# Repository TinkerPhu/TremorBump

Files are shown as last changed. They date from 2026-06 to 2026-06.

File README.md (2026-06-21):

TremorBump

# Tremor-Synchronized Stimulation Project

> ⚠ **This device applies up to 40 V electrical stimulation to the human body.
> Read [SAFETY.md](SAFETY.md) before building or using it.**

**[Open Companion App](https://tinkerphu.github.io/TremorBump/CompanionApp/tremor_recorder.html)**

This project implements a wearable device that detects hand/arm tremor in
real time and delivers phase-locked electrical stimulation in sync with the
tremor cycle, plus a companion web app for recording, reviewing, and
exporting telemetry from the device over Bluetooth Low Energy (BLE).

**KUDOS to the following projects that were the main inspiration:**

- **[DIY Transcutaneous Spinal Stimulator Guide](https://www.scribd.com/document/766706842/An-easy-to-build-transcutaneous-electrical-stimulator-for-spinal-cord-stimulation-therapy)**
- **[OpenVstim](https://github.com/MonzurulAlam/OpenVstim)**

See [`docs/References.md`](docs/References.md) for more sources.

## AI-generated content

Most of the code and documents in this project are AI-generated, based on the references listed in [`docs/References.md`](docs/References.md).

## Background and motivation

The author of this project has **no medical background**. The motivation is personal: helping family members who suffer from Essential Tremor. The project is an attempt to understand the condition and build a practical, low-cost tool to explore phase-locked SES as a self-administered therapy.

The clinical background documents in `docs/` were compiled with the help of **[NotebookLM](https://notebooklm.google.com/)**, using the references listed in `docs/References.md` as source material. They represent a best-effort synthesis of the available literature — not medical advice.

- [`docs/SES_Overview.md`](docs/SES_Overview.md) — plain-language introduction: what SES is, how it works, expected sensation, and efficacy overview.
- [`docs/SES_Clinical_Reference.md`](docs/SES_Clinical_Reference.md) — full technical reference: neurophysiology, fiber targets, electrode placement, stimulation parameters, clinical protocol, and outcome data.

> **None of this constitutes medical advice.** Consult a qualified healthcare professional before using any electrical stimulation device.

**It consists of four parts:**

1. **Hardware** — a wearable unit built around the Adafruit QT Py ESP32-S3,
   comprising two subsystems:
   - *Sensing:* an Adafruit BNO055 IMU measures gyroscope and quaternion data
     to detect tremor axis, frequency, and phase in real time.
   - *Stimulation:* a boost converter raises the supply to up to 40 V DC,
     which an H-bridge switches across skin-contact electrodes to deliver
     charge-balanced biphasic pulses synchronized to the tremor cycle.
2. **Tremor detection firmware** (`tremor_detection.py`) — runs on the device,
   detects tremor frequency/axis from the IMU, and drives the H-bridge to
   deliver biphasic stimulation pulses synchronized to the tremor.
3. **BLE telemetry** (`ble_telemetry.py`) — a custom BLE GATT service that
   advertises as `TREMOR` and streams live detector state to nearby devices.
4. **Tremor Recorder web app** (`tremor_recorder.html`) — a single-file,
   offline-capable HTML/JS app (Web Bluetooth + IndexedDB) for pairing with
   the device, recording sessions, charting live/aggregated data, and
   exporting/sharing results.

This is experimental code intended for use on isolated test hardware only.

```
TremorBump/
├── CircuitPython/          # Firmware — copy contents to the CIRCUITPY drive
│   ├── code.py
│   ├── tremor_detection.py
│   ├── ble_telemetry.py
│   ├── settings.toml
│   └── lib/                # Required CircuitPython libraries
├── CompanionApp/
│   ├── tremor_recorder.html
│   ├── manifest.json       # PWA manifest
│   ├── sw.js               # Service worker (offline cache)
│   ├── icon-192.png
│   └── icon-512.png
├── hardware/
│   ├── BOM.md              # Bill of materials
│   ├── TremorBumpBox.stl   # Main enclosure
│   ├── TremorBumpCog.stl
│   └── TremorBumpSensorBox.stl
└── docs/
    ├── References.md
    ├── SES_Overview.md
    ├── SES_Clinical_Reference.md
    └── conductive_electrode_gel_recipe.md
```

## Hardware required

- **Adafruit QT Py ESP32-S3** (4MB Flash / 2MB PSRAM variant,
  board ID `adafruit_qtpy_esp32s3_4mbflash_2mbpsram`). BLE is required, so the
  ESP32-S2 variant (no Bluetooth) will not work.
- **Adafruit BNO055** 9-DOF absolute orientation IMU, connected via I2C
  (`board.SCL` / `board.SDA`), used in NDOF fusion mode for gyro + quaternion
  data.
- **Boost converter** that steps the supply up to as much as **40 V DC**,
  feeding the H-bridge so it can drive the stimulation electrodes at
  therapeutic voltage.
- **H-bridge** driver for the stimulation electrodes, connected to
  `board.MOSI` (h_bridge_1) and `board.MISO` (h_bridge_2), switching the
  boosted 40 V supply to produce the stimulation waveform described below.
- **Stimulation electrodes** with conductive gel for skin contact. A DIY
  saline/glycerin/xanthan gel recipe is provided in
  [`docs/conductive_electrode_gel_recipe.md`](docs/conductive_electrode_gel_recipe.md).
- Onboard **NeoPixel** LED, used to indicate detector state (unlocked /
  locking / locked / holdover) and stimulation polarity.
- A BLE-capable computer or phone with a Chromium-based browser (Chrome /
  Edge) supporting Web Bluetooth, to run `tremor_recorder.html`.

## Firmware: required libraries

CircuitPython **10.2.0** with the following libraries in `lib/`:

- `adafruit_ble` — BLE radio, advertising, GATT services/characteristics
- `adafruit_bno055` — BNO055 IMU driver (gyro + quaternion)
- `adafruit_register` — register access helpers (dependency of the BNO055
  driver)
- `adafruit_pixelbuf` and `neopixel` — onboard NeoPixel status LED

Plus the CircuitPython built-in modules `board`, `busio`, `digitalio`,
`supervisor`, `math`, `time`, and `struct`.

The firmware entry point is `code.py`, which simply does
`import tremor_detection`.

## How tremor detection works (`tremor_detection.py`)

The detector samples the BNO055 gyroscope at **75 Hz** and runs a state
machine with four states:

- **UNLOCKED** — no tremor signal detected yet.
- **LOCKING** — a candidate tremor axis and frequency are being established;
  requires several alternating zero-crossings (4 from cold start, 2 when
  re-locking after holdover) within a timeout.
- **LOCKED** — tremor axis, frequency, and phase are tracked continuously;
  stimulation bursts are scheduled phase-correctly at each detected
  zero-crossing, with dead-reckoning between crossings.
- **HOLDOVER** — if the signal is lost while locked, stimulation continues at
  the last known frequency (at reduced duty cycle) via dead-reckoning for up
  to 5 seconds before falling back to UNLOCKED.

Key processing steps per sample:

1. Remove slowly-adapting gyro DC bias.
2. Optionally rotate gyro readings into world frame using the BNO055
   quaternion, so arm movement doesn't distort the tremor axis estimate.
3. Track the dominant tremor axis with a 3-D direction EWMA (fast time
   constant while locking, slow once locked).
4. Project motion onto that axis and track an amplitude envelope; detect
   hysteretic zero crossings with linear interpolation for precise timing.
5. Estimate tremor frequency (2–8 Hz) from alternating half-periods and use
   it to phase-correct the stimulation schedule.

When a stimulation event fires, `run_biphasic_burst()` drives the H-bridge
with a symmetric biphasic pulse train (250 µs phases, 1 µs interphase gap,
200 Hz internal pulse rate) for a duration proportional to the current tremor
period and a configurable duty cycle (halved during holdover).

### Stimulation waveform

A boost converter raises the device's supply to up to **40 V DC**. The
H-bridge switches this 40 V rail across the wrist electrodes to produce a
**biphasic (alternating-polarity) square-wave pulse train**: each pulse
consists of a 250 µs positive phase, a 1 µs interphase gap, and a 250 µs
negative phase, repeating at an internal pulse rate of 200 Hz. This biphasic
shape keeps the pulses charge-balanced (no net DC component), which is the
standard approach for safe transcutaneous nerve stimulation. Bursts of these
pulses are timed to coincide with the detected tremor cycle (locked) or its
extrapolated continuation (holdover), with a burst duration of
`duty_cycle / tremor_hz` — i.e. a fixed fraction (12.5%, or 6.25% during
holdover) of each tremor period — so the stimulation pulses the wrist nerves
in sync with, and proportional to, the ongoing tremor.

The onboard NeoPixel shows blue (unlocked), yellow (locking), off
(locked/holdover, with brief flashes on each stimulation burst showing
polarity).

## BLE telemetry protocol (`ble_telemetry.py`)

The device advertises as **`TREMOR`** with a custom 128-bit GATT service:

- Service UUID: `7f6d0001-6f7a-4f4e-9a8b-3b7f4b000001`
- Telemetry characteristic UUID: `7f6d0002-6f7a-4f4e-9a8b-3b7f4b000001`
  (read + notify)

The device name is placed in the BLE scan response (not the main
advertisement) so the custom service UUID fits in the primary advertisement
packet, allowing Web Bluetooth to discover the service by UUID.

While connected, the device sends a **13-byte, little-endian notify packet**
at 2 Hz (`BLE_NOTIFY_HZ`):

| Field | Type | Notes |
|---|---|---|
| `device_t_ms` | uint32 | raw device milliseconds, wraps ~49 days |
| `state_code` | uint8  | 0=UNLOCKED 1=LOCKING 2=LOCKED 3=HOLDOVER, 255=unknown |
| `sched_hz_x100` | uint16 | scheduling frequency × 100 (0.01 Hz resolution) |
| `tremor_hz_x100`| uint16 | measured tremor frequency × 100 (0.01 Hz resolution) |
| `mag_env_x10` | uint16 | 3-D gyro magnitude envelope × 10 (0.1 deg/s resolution) |
| `stim_count` | uint16 | cumulative stimulation count, wraps at 65535 |

The ESP-IDF BLE stack runs as a background FreeRTOS task, so the connection
stays alive even during the brief (~30 ms) blocking stimulation bursts.

## Hosting the web app (GitHub Pages + PWA)

The companion app is a fully static single-file app and can be hosted for
free on GitHub Pages.

### Enable GitHub Pages

1. Go to your repo on GitHub → **Settings** → **Pages**.
2. Source: **Deploy from a branch** → `main` → `/ (root)` → **Save**.
3. After a minute the app will be live at:
   `https://<your-username>.github.io/<repo-name>/CompanionApp/tremor_recorder.html`

GitHub Pages serves over HTTPS, which is required for both Web Bluetooth and
PWA installation.

### Install as a mobile app (Android)

Open the URL above in **Chrome on Android**, then tap the browser menu →
**Add to Home screen**. The app installs as a standalone icon with no browser
chrome, caches itself for offline use, and connects to the device over BLE
exactly as in the browser.

> **iOS note:** Web Bluetooth is not supported on iOS (Safari or Chrome on
> iPhone/iPad). The app can be added to the home screen on iOS but will not
> be able to connect to the device.

## Tremor Recorder web app (`tremor_recorder.html`)

A single-file, no-build-step, offline-capable web app (HTML + CSS + vanilla
JS) that connects to the `TREMOR` device over Web Bluetooth, records
telemetry sessions, and lets you review/export them. Works on desktop
(Chrome/Edge) and mobile Chrome on Android.

### Pairing & connection

- The device picker is filtered to devices whose advertised name starts with
  `TREMOR`, using `filters: [{ namePrefix: "TREMOR" }]`.
- The GATT connection is kept open across recording sessions (not
  re-paired/torn down after each stop), and silently reconnects if dropped.

### Screens

- **Start** — primary card with status line, a large "Start recording" button
  and a "Sessions" button; secondary card (scroll to reach) with
  Export / Admin / Settings and an optional "Run simulated session" button.
- **Recording** — primary card with large live Magnitude and Tremor frequency
  tiles, a "Stop & save" button, and a status/error line, all fitting on
  screen without scrolling; secondary card (scroll to reach) shows
  Stimulation count, Sched frequency, State, and Samples recorded.
- **Session saved** — large "Start new recording" button (reuses the existing
  BLE connection, or pairs first if needed) plus a summary and a link to
  review the saved session.
- **Review** — shows session summary and two SVG charts (Tremor frequency,
  Magnitude) plotting the per-interval average as a line with the min/max
  range as a shaded band. The Y-axis is scaled to 80%–120% of the average's
  min/max to avoid outlier samples dominating the scale.

### Data storage (IndexedDB: `tremor_recorder_db`)

- `sessions` — one record per recording session (start/stop times, device
  name, disconnect reason, config snapshot, sample count).
- `samples` — one record per telemetry packet received (timestamps, state,
  scheduled/tremor frequency, magnitude, stim count).
- `aggregates` — per-interval (default 10 s, configurable) min/avg/max
  statistics for tremor frequency and magnitude, plus active-stim coverage.

### Export & sharing

- CSV export of raw samples and JSON export of session summaries/aggregates.
- On desktop, both exports download as files.
- On mobile, "Share raw samples (CSV)" and "Share summary (JSON)" open the
  native share sheet (the JSON is shared as a `.txt` file due to Chromium
  share-target restrictions on `.json`/`application/json`).

### Simulation mode

Appending `?simulate=1` to the URL enables a "Run simulated session" button
that generates synthetic telemetry without requiring a real device — useful
for UI testing.

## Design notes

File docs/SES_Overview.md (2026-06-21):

# Sensory Electrical Stimulation (SES) — Overview and Clinical Background

Sensory Electrical Stimulation (SES) is a non-invasive neuromodulation technique that delivers low-level electrical currents through the skin at intensities below the motor threshold — providing sensory feedback without causing muscles to twitch or contract. This project uses SES to target **Essential Tremor (ET)**, the most common movement disorder in older adults, characterised by a rhythmic action/postural tremor of the hands at 5–8 Hz.

> SES has also been studied as a therapy for Parkinson's disease (PD) tremor, and the TremorBump device could in principle be applied there as well. However, ET is the focus of this project.

## How SES Works

Surface electrodes are placed over major nerves at the wrist (median and radial nerves) or over motor points on the forearm muscles. These electrodes deliver electrical pulses — often organised into high-frequency bursts — to disrupt pathological signals in the Cerebello-Thalamo-Cortical (CTC) circuit, which governs tremor amplitude in ET. By sending artificial sensory signals into this circuit, SES can "jam" or dephase the rhythmic oscillations that drive the involuntary hand movements.

## Expected Sensation

The patient should feel a **strong but comfortable tingling or tickling** sensation in the hand or fingers. Intensity must be set individually to stay at this sensory level — it should never cause an electric shock sensation or visible muscle contraction.

## Therapy Sessions

| Parameter | Typical value |
|---|---|
| Session length | 20–40 minutes |
| Frequency | 3× per week to daily |
| Duration of effect | Immediate; can persist >1 hour after stimulation ends |

Repeated daily use over months does not appear to lead to a loss of the lasting post-stimulation effect.

For the full technical detail — fiber types, electrode landmarks, stimulation parameters, and clinical outcomes — see [`SES_Clinical_Reference.md`](SES_Clinical_Reference.md).

## Estimated Efficacy

The figures below come primarily from studies on PD and general tremor populations, as large-scale ET-specific SES trials remain limited. The underlying mechanism (CTC circuit modulation) is shared with ET, so the results are considered indicative.

| Scenario | Tremor reduction |
|---|---|
| General SES | 35–48% average reduction |
| Calibrated therapies (e.g. TAPS) | >90% of patients see some reduction; majority achieve ≥50% decrease in tremor power |
| Phase-locked stimulation, severe tremors | 60–65% reduction in tremor power |
| Combined with physical therapy, suitable responders | Up to 83% average magnitude decrease |

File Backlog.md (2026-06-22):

# Backlog

---

## Main Goal

The current firmware fires a stimulation burst at **every** zero-crossing of the detected tremor angular velocity — i.e. at both π/2 and 3π/2 per cycle. This made sense as a placeholder and is correct for a future dual-channel 4-electrode system where the two channels fire in antiphase. For the current **single-channel 2-electrode system it is clinically wrong**: it stimulates twice per tremor cycle, which disrupts the phase-lock rather than reinforcing it.

**The goal of all three features below is to make the device fire at exactly one zero-crossing per tremor cycle — the one where the arm is moving closest to the body — and to determine that zero-crossing automatically from the sensor data and a one-time arm-side configuration set in the companion app.**

If arm side is not configured, the device does **not** stimulate at all. There is no automatic detection, no fallback to both phases, and no ambiguous state. The companion app is the right place to set and confirm arm side.

The three features must be delivered in order. Each is independently testable.

---

## Feature 1 (Prerequisite): BLE Settings Characteristic

### Goal

Allow the companion app to read and write persistent device settings over BLE. This is the communication layer that all subsequent features depend on. Nothing else in this backlog can be built without it.

### Context

The existing BLE GATT service (`7f6d0001`) has one characteristic:
- `7f6d0002` — telemetry, **notify + read**, device → app, 13 bytes (unchanged).

A second characteristic is added to the same service:
- `7f6d0003` — settings, **read + write**, bidirectional, 8-byte versioned struct.

The telemetry packet is **not** extended. Settings are read once on connect and trusted for the duration of the session. The session record stores the settings bytes as a header so every recording is self-describing.

### Settings Struct v1

All bytes little-endian. Total: 8 bytes.

| Byte | Field | Type | Values | Default |
|---|---|---|---|---|
| 0 | `struct_version` | uint8 | 1 | 1 |
| 1 | `arm_side` | uint8 | 0 = not set, 1 = left, 2 = right | 0 |
| 2 | `fire_polarity_override` | uint8 | 0 = auto, 1 = positive crossing, 2 = negative crossing | 0 |
| 3–7 | *(reserved)* | uint8 × 5 | 0xFF | 0xFF |

`struct_version` must be incremented whenever the layout changes. App and firmware both check it and handle mismatches gracefully.

### App ↔ Device Protocol

**On every BLE connection (before Settings screen is usable):**
```
App connects
  → Read 7f6d0003 (8 bytes)
  → Check struct_version
      - Unknown version (device newer than app): show notice, disable writes, show read-only values
      - Known version: update Settings UI, cache struct in session memory as deviceSettings
```

**On every user-initiated setting change:**
```
User changes value in Settings screen
  → Merge change into cached deviceSettings struct (never build struct from UI state alone)
  → Write full 8-byte struct to 7f6d0003 (write-with-response)
  → Wait 300 ms
  → Read back 7f6d0003
  → Compare: match → show "Saved"; mismatch → show error, revert UI to read-back value
```

**Settings are never stored in the app's localStorage or IndexedDB. The device NVM is the single source of truth. The app always reads from the device on connect.**

### Session Data Header

When a session starts, the app reads the current `deviceSettings` object (already cached from connect-time read) and stores it as part of the session record in IndexedDB:

```
session.deviceSettings = {
  structVersion: 1,
  armSide: 1,          // 0 = not set, 1 = left, 2 = right
  firePolarityOverride: 0,
  rawBytes: [1, 1, 0, 255, 255, 255, 255, 255]  // full 8-byte struct as recorded
}
```

This is included in every JSON export under `session.deviceSettings`. It means any recording is fully self-describing: the settings active during that session are always available, regardless of what the device is configured to later.

### Firmware Implementation Plan (`ble_telemetry.py`)

- Add `7f6d0003` to the existing GATT service with read + write-with-response permissions.
- On **read**: assemble 8-byte struct from `microcontroller.nvm[0:8]`. If any byte is 0xFF (uninitialised), substitute the field's default before returning.
- On **write**: validate `struct_version` matches firmware's expected version — reject silently if not. Validate each field is within allowed range — clamp out-of-range values. Write validated fields to `microcontroller.nvm[0:8]`. Apply fields that take immediate effect (see Feature 2 for `arm_side`).
- Reserve `microcontroller.nvm[0:8]` exclusively for this struct. Any future NVM use starts at index 8.

### Companion App Implementation Plan (`tremor_recorder.html`)

- On BLE connect, read `7f6d0003` immediately. Settings screen shows a loading state until read completes.
- Cache result in session-scoped JS object `deviceSettings`. All writes merge into this object.
- On session start (`startRecording()`): copy current `deviceSettings` into the new session record.
- Settings screen gains a "Device settings" section (separate from the existing app-local aggregate interval / stim-window settings which remain in localStorage):
  - **Arm side**: Left / Right / Not set (maps to 1 / 2 / 0)
  - **Phase override**: Auto / Force positive crossing / Force negative crossing (collapsible, labelled "research use only")
- Write → read-back → confirm / error as per protocol above.
- On BLE disconnect during a write in progress: show error, re-read on reconnect before enabling further writes.
- Session export JSON: include `deviceSettings` under each session.

### Documentation Plan

- Help screen and `docs/`: explain that "Device settings" are stored on the device, survive power cycles, and are separate from app-local session settings. Explain that every exported recording carries the device settings that were active during that session.

### Open Questions

- [ ] 300 ms read-back delay: verify empirically that `microcontroller.nvm` write completes within this window on the QT Py ESP32-S3.
- [ ] Write-with-response: confirm CircuitPython's `adafruit_ble` supports this on the peripheral side.
- [ ] Security: no write protection planned for now. Revisit if used in a clinical setting.

---

## Feature 2: Arm-Side Configuration

### Goal

The device must know which arm it is on (left or right) so that Feature 3 can select the correct stimulation phase. The arm side is set once in the companion app and stored persistently in device NVM. If it is not set, the device does not stimulate.

### User Story

> As a patient or carer, I configure which arm the device is on once in the companion app. The device remembers it across power cycles. If it is not set, the app tells me clearly and no stimulation happens until I configure it.

### Mechanism

1. Patient (or carer) connects the companion app.
2. Opens Settings → selects Left or Right arm.
3. App writes `arm_side` field to the device via `7f6d0003`.
4. Firmware writes to NVM.
5. On every subsequent power-on, device reads NVM and has arm side immediately. No calibration, no detection, no posture.

If `arm_side == 0` (not set): the app shows a clear, prominent message — "Arm side not configured. Go to Settings to set it before starting a session." The Start recording button is disabled until arm side is set.

### Firmware Implementation Plan (`tremor_detection.py` + `ble_telemetry.py`)

- `tremor_detection.py`: on startup, read `microcontroller.nvm[1]` into `arm_side`. Expose `arm_side` to the BLE module.
- `ble_telemetry.py`: when the settings characteristic receives a write with a new `arm_side` value, write to `microcontroller.nvm[1]` and update the RAM variable immediately (takes effect in the current session without restart).
- `arm_side = 0`: the device reaches LOCKED state but does not call `run_biphasic_burst()`. No stimulation occurs. This is not an error state — it simply means the device has not been configured yet.

### Companion App Implementation Plan

- On connect: read `7f6d0003`. If `arm_side == 0`: show a clear prominent message on the start screen "Arm side not set — configure in Settings before recording." Disable the "Start recording" button.
- Start recording is only enabled when `arm_side` is 1 or 2.
- Settings screen: arm-side selector as described in Feature 1.
- Session export: `deviceSettings.armSide` is in every session record (via Feature 1 session header).

### Documentation Plan

- Help screen: explain that arm side must be set once before first use. Explain what happens if it is not set (no stimulation, app shows message).
- Manual: add sensor placement rule — device must always be on the **dorsal (back) side** of the wrist, with the marked end pointing toward the hand. This is a hard constraint: wrong placement inverts the phase selection in Feature 3.

### Open Questions

- [ ] NVM byte index: `arm_side` is at `microcontroller.nvm[1]` (byte 1 of the settings struct, after `struct_version` at byte 0). Confirm all startup code reads byte 1, not byte 0.
- [ ] "Not set" UX: should the Settings screen open automatically if arm side is not set when first connecting? Consider an onboarding flow for first use.

---

## Feature 3: Phase-Correct Stimulation (Single Phase per Cycle)

### Goal

This is the main goal of the entire backlog. Once the arm side is known (Feature 2), the firmware derives the correct zero-crossing polarity (positive or negative) to use as the stimulation trigger and fires **once per tremor cycle** at that crossing only.

### User Story

> As a patient, I want the device to fire one stimulation pulse per tremor cycle — at the moment my arm is moving closest to my body — so that the therapy correctly interrupts the tremor feedback loop instead of reinforcing it.

### Acceptance Criteria

1. With arm side set and sensor correctly placed (dorsal, mark toward hand), stimulation fires exactly once per tremor cycle.
2. The firing zero-crossing corresponds to the arm moving toward the body.
3. Behaviour is mirrored correctly for left vs. right arm.
4. If arm side is not set (`arm_side == 0`): device locks on to tremor but does not stimulate. App shows "Arm side not set — no stimulation active."
5. The phase can be overridden manually from the app Settings (research/diagnostic use only).
6. Stimulation count in telemetry increments once per cycle (previously twice).

### Phase Selection Logic

The BNO055 gyroscope measures angular velocity in its own sensor frame. The firmware already identifies the dominant tremor axis as a 3D unit vector. The angular velocity projected onto this axis oscillates at the tremor frequency; zero-crossings mark the turning points of the tremor cycle.

The two zero-crossings per cycle are:
- **Positive-going** (velocity crosses zero from negative to positive): arm reverses direction one way.
- **Negative-going** (velocity crosses zero from positive to negative): arm reverses direction the other way.

Which one corresponds to "arm moving toward body" depends on:
1. **Arm side (left/right)**: mirrors the anatomical rotation axis.
2. **Sensor placement**: sensor on the dorsal side with mark toward the hand — this fixes the sign convention. This is a hard constraint documented in Feature 2.

> ⚠ **Posture constraint for phase computation:**  
> The gravity vector provides up/down orientation. "Toward the body" is a roughly horizontal direction. For the derivation to work reliably, the arm should be approximately horizontal (extended forward or to the side) at the moment the device locks in. The firmware computes `fire_polarity` once at the LOCKED transition using the gravity vector at that instant. If the arm is near-vertical at lock-in, the gravity projection onto the tremor plane is weak — treat this as a degenerate case and do not stimulate until re-lock with a better posture.

**Derivation (to be validated on hardware before coding):**
1. At LOCKED transition: read gravity vector `g` and dominant tremor axis unit vector `t` (both from BNO055 NDOF output).
2. Project `g` onto the plane perpendicular to `t`: `g_perp = g − (g·t)t`. This gives the "downward" direction as seen from the tremor axis.
3. The "toward body" rotational direction = cross product of `t` and `g_perp`, sign-corrected for arm side (negated for left arm).
4. Compare this direction to the sign of the angular velocity projection at lock-in to select `fire_polarity`.

### Firmware Implementation Plan (`tremor_detection.py`)

- On transition to `LOCKED` state:
  - If `arm_side == 0` (not set): set `fire_polarity = NONE`. Do not call `run_biphasic_burst()` at any zero-crossing.
  - If `arm_side` is known (1 or 2) and `fire_polarity_override == 0`: compute `fire_polarity` using the derivation above.
  - If `fire_polarity_override != 0`: use override value directly.
  - If gravity projection is too weak (degenerate posture): set `fire_polarity = NONE`, do not stimulate.
- In `LOCKED` and `HOLDOVER` states: only call `run_biphasic_burst()` at zero-crossings matching `fire_polarity`. Skip all other crossings.
- Re-compute `fire_polarity` at each re-lock. The arm may have moved.
- **Do not extend the telemetry packet.** `fire_polarity` and `arm_side` are available to the app via the settings characteristic and the session header.

### Companion App Implementation Plan

- Recording screen: show "Arm side" (from `deviceSettings` cached at connect time) as a small read-only status field. No telemetry bytes needed — this comes from the settings read.
- If `deviceSettings.armSide == 0` and a recording is started (should be blocked by Feature 2, but as defence): show a persistent red warning on the recording screen "Arm side not set — device is not stimulating."
- Settings screen "Phase override" (from Feature 1): Auto / Force positive / Force negative. Labelled "Research / diagnostic use only."
- Session export: `deviceSettings.firePolarityOverride` is already in the session header from Feature 1.
- Stimulation count metric: relabel from "Stimulation count" to "Stimulation bursts".

### Documentation Plan

- Help screen: brief explanation that the device selects the stimulation phase automatically from the sensor and arm-side configuration. No user action needed beyond setting arm side once.
- Help screen: "If arm side is not set, the device detects your tremor but does not deliver stimulation. Set arm side in Settings."
- Manual: technical note on the phase-selection mechanism.

### Dependencies

- Feature 3 cannot start until Feature 2 is complete and `arm_side` is reliably written to NVM and read by firmware.
- **The phase derivation math must be validated on paper and on the physical device before writing any firmware.** Document the exact BNO055 axis convention (X/Y/Z vs. anatomical forearm axes) first.

### Open Questions

- [ ] Work out and document the BNO055 coordinate frame. Which sensor axis is along the forearm, which is lateral, which is dorsal-normal. This is the foundation of the entire derivation — get it wrong and the phase is inverted.
- [ ] Define "toward body" precisely for the expected tremor type. Essential Tremor typically involves pronation/supination and flexion/extension of the wrist. Is the therapeutically relevant motion adduction or flexion? May need per-patient validation in early trials.
- [ ] Degenerate posture threshold: how small does `|g_perp|` need to be before we consider the posture degenerate? Suggested: if `|g_perp| < 1.0 m/s²` (arm within ~6° of vertical), do not stimulate and log the reason.
- [ ] Amplitude-comparison validation: after shipping, consider an optional diagnostic mode where the device alternates phases for N cycles each and the app reports the tremor amplitude change. This lets a clinician verify the chosen phase actually reduces tremor, or flip it if not.
- [ ] Stimulation count relabelling: confirm "bursts" vs. "count" does not break comparison of old vs. new session exports for any ongoing trials.

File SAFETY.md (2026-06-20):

# Safety Warning

This is an **experimental, uncertified device** that applies electrical
stimulation to the human body at up to **40 V DC** through skin-contact
electrodes. It has **no medical certification or regulatory approval** of any
kind (no FDA clearance, no CE mark).

## Known risks specific to this design

- **Electric shock and burns.** 40 V through skin-contact electrodes can cause
  skin burns, nerve damage, or cardiac arrhythmia — particularly if electrodes
  shift, gel dries out, or skin impedance is locally high.
- **No hardware kill switch.** Stimulation continues if the phone disconnects
  or the firmware hangs. A firmware crash mid-burst may leave the H-bridge
  outputting continuous DC rather than balanced biphasic pulses, which causes
  electrochemical burns.
- **No current limiting.** There is no hardware circuit to cap delivered
  current. Electrode placement, gel quality, and skin condition directly
  determine what reaches your tissue.

## Contraindications

Do not build or use this device if you have any of the following:

- Cardiac conditions or arrhythmia history
- A pacemaker, implanted defibrillator, or any other implanted electronic device
- Epilepsy
- Pregnancy
- Broken, irritated, or damaged skin at the intended electrode site

## Rules for use

- Use only on yourself. Do not use on another person without their explicit,
  informed consent and without them having read this document.
- Never place electrodes near the chest, neck, or head.
- Always have a second person present who can physically remove the electrodes
  or cut power in an emergency.
- Stop immediately if you experience unexpected sensations, pain, or muscle
  contractions outside the intended wrist area.
- Do not use while alone, while fatigued, or while impaired.
- Inspect electrodes and gel before every session. Do not use if gel has dried,
  if electrodes have shifted, or if the skin at the contact site is irritated.

## Liability

The author(s) of this project accept no liability whatsoever for injury,
damage, or any other harm resulting from building, modifying, or using this
design. **You build and use it entirely at your own risk.**

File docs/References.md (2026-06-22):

## AI Help

- All my research was done with [NotebookLM]

## Main inspiration

- [OpenVstim](https://github.com/MonzurulAlam/OpenVstim) Kudos to Monzurul Alam, your project was extremely helpful!
- [DIY Transcutaneous Spinal Stimulator Guide](https://www.scribd.com/document/766706842/An-easy-to-build-transcutaneous-electrical-stimulator-for-spinal-cord-stimulation-therapy)

## Medical Sources

### Phase-Locked Patterns
- [Journal of Personalized Medicine: Analyzing the Effects of Parameters for Tremor Modulation via
Phase-Locked Electrical Stimulation on a Peripheral Nerve](https://pdfs.semanticscholar.org/c826/ad993e6e30be93256aaaec5187903c1e6592.pdf)

### Calibrated and Systematic Patterns
- [Non-Invasive Electrical Stimulation of Peripheral Nerves for the Management of Tremor](https://pmc.ncbi.nlm.nih.gov/articles/PMC9590374/)

### Carrier and Burst Frequencies
- [Peripherical Electrical Stimulation for Parkinsonian Tremor: A Systematic Review](https://pmc.ncbi.nlm.nih.gov/articles/PMC8859162/)

### Clinical Success Rates (Systematic Data): Source 11/19 (Meng et al.)
- [Peripherical Electrical Stimulation for Parkinsonian Tremor: A Systematic Review](https://pmc.ncbi.nlm.nih.gov/articles/PMC8859162/)

### Therapy Recommendations (The TAPS Model): Source 5 (Pascual-Valdunciel et al.)
- [Peripherical Electrical Stimulation for Parkinsonian Tremor: A Systematic Review](https://pmc.ncbi.nlm.nih.gov/articles/PMC8859162/)

### Specific PD Success Rates
- [Effect of Sensory Electrical Stimulation on Resting Tremors in 
Patients with Parkinson's Disease](https://theaspd.com/index.php)

## 3d Modeling:
- Kudos to [3dprintgenerator](https://3dprintgenerator.com/3d-printable-box-generator) for providing me with boxes for the prototype.
- tinkercad.com: [link to my prototype](https://www.tinkercad.com/things/3hKN6EKuy5i-tremorbox?sharecode=N-AWgftHCy6_xc6FceFQzlX0g8878zCJa26oigJ_DyM).

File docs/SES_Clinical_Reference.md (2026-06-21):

# SES for Hand Tremors in Senior Patients — Clinical Summary

Sensory Electrical Stimulation (SES) is a non-invasive neuromodulatory intervention that delivers electrical current at intensities below the motor threshold (MT) to engage sensory feedback loops without inducing overt muscle contractions. This project applies SES to **Essential Tremor (ET)** — the most prevalent movement disorder in seniors, producing a rhythmic action/postural hand tremor typically in the **5–8 Hz** range (full pathological range: 4–12 Hz).

> For a plain-language introduction to SES, see [`SES_Overview.md`](SES_Overview.md).

> Much of the published clinical SES literature focuses on Parkinson's disease (PD) tremor. The TremorBump device is mechanistically applicable to PD as well, but ET is the scope of this project. The clinical data cited below is drawn from PD and mixed-tremor studies where ET-specific data is limited; the neurophysiological mechanism (CTC circuit modulation) is shared between both conditions.

SES is distinguished from related modalities by its neurophysiological targets:

| Modality | Intensity vs. Motor Threshold | Primary Mechanism | Typical Frequency |
|---|---|---|---|
| **SES** | Below (sub-motor) | Central sensorimotor integration via proprioceptive afferents | 50–100 Hz |
| **FES** | Above | Induced muscle contraction | 20–40 Hz |
| **TENS** | Below | Inhibition via cutaneous afferents | 100–250 Hz |

---

## Technical Mechanisms and Neurophysiological Pathways

### Selective Fiber Activation

SES targets **Type Ia and Type Ib proprioceptive sensory fibers**. These fibers sit anatomically deeper than cutaneous afferents, requiring lower excitation levels to achieve central suppression:

- **Type Ia** — promotes reciprocal inhibition, enhancing agonist muscle control while reducing antagonistic co-activation.
- **Type Ib** — modulates the spinal stretch reflex through Ib inhibition.

### Central Circuit Modulation — the "Dimmer-Switch" Hypothesis

ET tremor is driven primarily by the **Cerebello-Thalamo-Cortical (CTC) circuit**, which governs tremor amplitude. SES provides artificial sensory feedback that interferes with the thalamic and cerebellar receptive fields within this circuit, "dimming" the pathological oscillations that produce the involuntary hand movement.

### Electrode Placement — Motor Points for Hand Tremor Suppression

| Muscle | Landmark |
|---|---|
| Flexor Carpi Radialis (FCR) | 4 fingerbreadths distal to the bicep tendon |
| Extensor Carpi Radialis (ECR) | 2 fingerbreadths distal to the lateral epicondyle |
| Flexor Carpi Ulnaris (FCU) | Junction of the middle and upper thirds of the forearm, volar to the ulna |

---

## Therapeutic Parameters and Clinical Protocol

### Stimulation Parameters

| Parameter | Value |
|---|---|
| Waveform | Biphasic square wave (charge-balanced; prevents tissue damage) |
| Trigger phase | Locked to ±amplitude peaks of the tremor cycle (½π and 1½π) |
| Duty cycle | 12.5% of the tremor period per burst |
| Carrier frequency | 100 Hz |
| Pulse width | 250 µs (Abass et al., 2025) or 300 µs (Heo et al.) |
| Intensity adjustment | 0.2 mA incremental steps, individualised to stay below motor threshold |

### Administration Schedule

| Parameter | Value |
|---|---|
| Session duration | 20–40 minutes |
| Weekly frequency | 3 sessions per week |
| Total treatment duration | 4 weeks (minimum 12 sessions) |

Cumulative treatment over a 4-week protocol facilitates circuit stabilisation. While acute relief is transient, tremor reduction typically persists for **1+ hour post-stimulation** following consistent administration.

---

## Patient Experience and Sensation Benchmarks

- **Target sensation:** a **strong but comfortable tingling or tickling** in the hand or fingers. This confirms the sensory threshold has been reached without crossing into motor territory.
- **Motor threshold signs:** visible muscle twitches or an electric shock sensation — intensity must be reduced immediately if either occurs.

> **Important:** SES must remain strictly below the motor threshold. Stimulation reaching motor levels can paradoxically worsen tremors by increasing patient anxiety and inducing muscle fatigue.

---

## Clinical Efficacy

The figures below are drawn from studies on mixed tremor and PD populations, as ET-specific SES trials remain limited. The CTC mechanism targeted here is shared with ET.

| Population / Scenario | Result |
|---|---|
| General SES (mixed tremor populations) | 35–48% average tremor power reduction |
| Phase-locked to ±peaks (½π and 1½π), severe tremors | 60–65% reduction in tremor power |
| SES combined with physical therapy, suitable responders (Abass et al., 2025) | Up to 83% average magnitude decrease |
| Study cohort Group A | Highly significant reduction in tremor frequency (t = 10.114, P < 0.001) |

### Functional Improvements

- **Fahn-Tolosa-Marin (FTM) scores:** highly significant reductions (P < 0.001) in tremor severity following the 12-session protocol.
- **FTM writing scores:** marked improvement, indicating restored fine motor control for daily tasks.

---

## References

- Meng, L., Jin, M., Zhu, X., & Ming, D. (2022). *Peripherical Electrical Stimulation for Parkinsonian Tremor: A Systematic Review.* https://www.ncbi.nlm.nih.gov/pmc/articles/PMC8859162/
- Abass, M. Y., Badawy, M. S., Ahmed, G. M., Shendy, W., El-Jaafary, S. I., & Morsi, A. A. (2025). *Effect of Sensory Electrical Stimulation on Resting Tremors in Patients with Parkinson's Disease.* https://theaspd.com/index.php/ijes/article/download/7374/5335/15167
- Alam, M. (OpenMedTech Lab). *OpenVstim: Open Source Transcutaneous Voltage Stimulator.* https://github.com/MonzurulAlam/OpenVstim

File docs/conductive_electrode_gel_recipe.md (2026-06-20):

# Conductive Electrode Gel Recipe

## Purpose

This gel is intended for use between the skin and stimulation or sensing electrodes to:

- Improve electrical contact between electrode and skin
- Reduce electrode-skin impedance
- Remain hydrated longer than a simple salt-water gel
- Provide a stable, easy-to-apply gel consistency

**Warning:** This recipe contains **2% NaCl**. Some people may experience skin irritation, especially during prolonged use or electrical stimulation. If irritation occurs, discontinue use and consider reducing the salt concentration to approximately **0.9–1.0% NaCl**.

## Ingredients (100 g batch)

- 77 g distilled water
- 20 g glycerin
- 2 g sodium chloride (NaCl, table salt)
- 1 g xanthan gum

## Equipment

- Small mixing container
- Digital scale
- Whisk, milk frother, or immersion blender
- Storage container with lid

## Mixing Instructions

### Method 1 (recommended)

1. Weigh 77 g distilled water into a mixing container.
2. Add 2 g NaCl and stir until completely dissolved.
3. Add 20 g glycerin and mix thoroughly.
4. In a separate small cup, make a smooth slurry by mixing the 1 g xanthan gum with a small portion of the glycerin mixture.
5. Slowly add the xanthan slurry back into the main mixture while stirring vigorously.
6. Continue stirring for 1–2 minutes until evenly dispersed.
7. Allow the gel to rest for 15–60 minutes so the xanthan gum can fully hydrate.
8. Stir once more before use.

### Alternative Method

1. Dissolve the NaCl in the water.
2. Add the glycerin and mix.
3. Slowly sprinkle the xanthan gum into the liquid while stirring continuously.
4. Mix thoroughly and allow to hydrate for 15–60 minutes.

## Notes

- No heating is required.
- If the gel is too thick, add a small amount of distilled water.
- If the gel is too thin, add a little more xanthan gum.
- Store in a sealed container in the refrigerator.
- This recipe contains **no preservative**. Discard and make a fresh batch after
  **2 weeks**, or immediately if the gel develops odor, discoloration, mold, or
  any visible contamination.
- For longer shelf life, prepare small batches rather than storing large quantities.

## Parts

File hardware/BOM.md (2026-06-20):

## Prototype BOM (non-affiliate links):

- Micro Controller: Adafruit QT Py ESP32-C3 WiFi Dev Board with STEMMA QT, [adafruit](https://www.adafruit.com/product/5405)

- 9-DOF Absolute Orientation, BNO055: [adafruit](https://www.adafruit.com/product/2472) 
or any similar board with BNO055

- 9V Block Battery

- Boost Converter: XL6009 DC-DC Buck Boost Voltage Converter Power Module 4A 400KHz Adjustable Switch Module 3.8-30V to 1.25-35V Power Supply, [ali express](https://de.aliexpress.com/item/1005006839194019.html)

- H-Bridge: DRV8871 H-Bridge Brushed DC Motor Driver Breakout Board For Arduino PWM Control 3.6A Max Internal Current Sense 6.5V- 45V, [ali express](https://de.aliexpress.com/item/1005005559572513.html)
- Buck Converter: [ali express](https://de.aliexpress.com/item/33045814885.html). 
I used the variable one, but one fixed to 3.3V would be safer.

- 3.5mm, 4 Pin Plug, 320 327-Purple, [ali express](https://de.aliexpress.com/item/1005010744066483.html)
- 3.5mm, 4 Pin female socket, [ali express](https://de.aliexpress.com/item/1005008150971423.html)
- 2.5mm, 2 Pin female socket, PJ-201M, [ali express](https://de.aliexpress.com/item/1005005133693277.html)
- Bracers with cable, [ali express](https://de.aliexpress.com/item/1005006897360676.html)

- Electrodes, Electrostimulation Patches Tens Electrode Pads for EMS Muscle Stimulator Electric Massager Replacement Conductive Gel Sticker, 3x4.5cm 20pcs, [ali express](https://de.aliexpress.com/item/1005007809186835.html)

- ON/OFF Switch, Mini Size Black SPDT Toggle Switch 1P2T Slide Switch Handle High 4MM for Small DIY Power, [ali express](https://de.aliexpress.com/item/1005009946438127.html)

- 4 core shielded wire, 2 3 4 core shielded wire UL 2547 28AWG, [ali express](https://de.aliexpress.com/item/32926518660.html), 
(3 core + shield would be enough)

- one 3d printed box for electronics and battery
- one 3d printed box for gyroscope BNO055

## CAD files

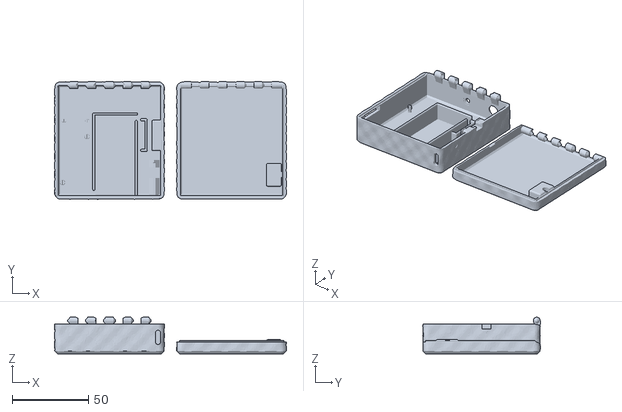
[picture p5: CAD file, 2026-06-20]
hardware/TremorBumpBox.stl
152.0 x 77.0 x 24.0

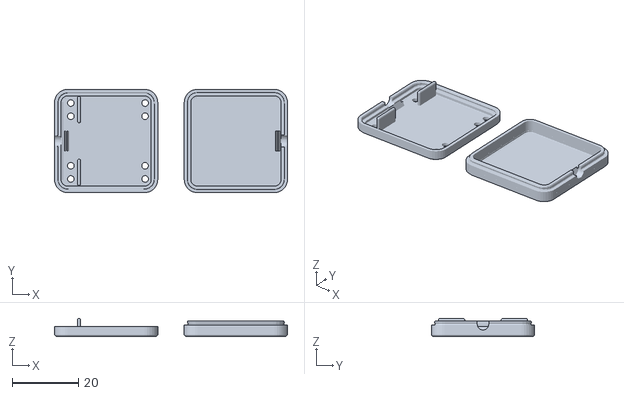
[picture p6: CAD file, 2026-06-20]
hardware/TremorBumpSensorBox.stl
70.6 x 31.3 x 5.50

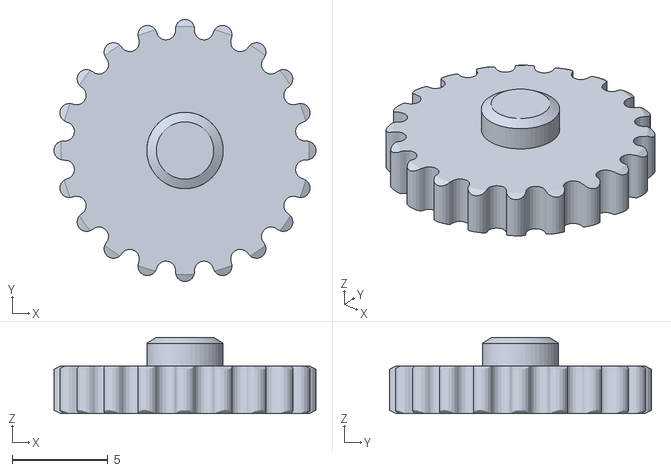
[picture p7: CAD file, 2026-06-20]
hardware/TremorBumpCog.stl
13.7 x 13.7 x 4.00

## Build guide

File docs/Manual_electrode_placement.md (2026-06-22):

This instruction manual details the placement of surface electrodes for **Sensory Electrical Stimulation (SES)** to manage Essential Tremor (ET). This therapy uses low-level current to target the sensory pathways leading to the brain's tremor control centers (thalamus and cerebellum).

---

### **Sensor Placement Rule**

The TremorBump device must always be worn on the **dorsal (back) side** of the wrist, with the **marked end pointing toward the hand**. This placement is required for the automatic phase selection to derive the correct stimulation timing. Placing the device differently inverts the phase logic.

- **Dorsal side**: the back of the wrist (same side as the knuckles), not the palm side.
- **Mark toward hand**: the arrow or notch on the device casing points toward the fingers, not the elbow.

---

### **Safety & Expectations**
*   **The Goal:** You should feel a **"strong but comfortable" tingling or tickling** sensation.
*   **The Limit:** Do **NOT** increase the power until the muscles twitch or the hand moves involuntarily. This is the **Motor Threshold (MT)**; SES must remain **sub-motor** (below that level).
*   **Skin Care:** Apply electrodes only to healthy, intact skin. Do **not** place them over rashes, sores, or areas with "razor burn" from shaving.
*   **Warning:** **Never** place electrodes across the chest, near the heart, or on the front of the neck.

---

### **Configuration A: 2-Electrode Setup (Single Channel)**
*Best for simple setups targeting a specific nerve branch to disrupt the tremor signal.*

| **Step** | **Patient Instructions (Normal Language)** | **Clinical Notes (Medical Language)** |
| :--- | :--- | :--- |
| **1. Target** | Focus on the **outer edge of your wrist**, on the same side as your thumb. | Target the **superficial branch of the radial nerve** at the lateral aspect of the wrist. |
| **2. Placement** | Place the two small round stickers about one inch apart along the bone on the thumb-side of your wrist. | Apply a pair of **0.8-inch circular electrodes** longitudinally over the radial nerve path near the styloid process. |
| **3. Testing** | Turn on the device slowly. You should feel tingling on the **back of your hand and your thumb**. | Confirm placement via **sensory mapping**; stimulus should correspond to the radial nerve's cutaneous distribution. |

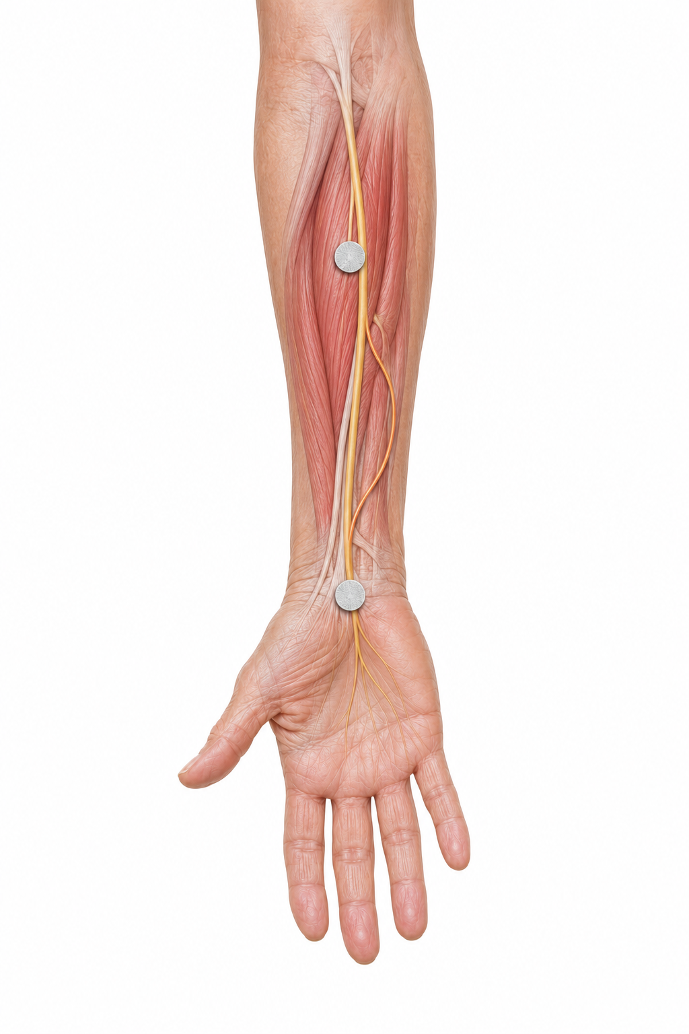
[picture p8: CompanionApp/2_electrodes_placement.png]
2-electrode placement on the radial nerve path along the palm-side forearm


---

### ~~**Configuration B: 4-Electrode Setup (Dual Channel)**~~

> ⚠ **Not yet implemented — hardware limitation:** Configuration B requires two independent H-bridge circuits so that the inner electrode pair (Channel 1 – Flexors) and outer electrode pair (Channel 2 – Extensors) can fire with a 180° phase offset from each other. The current TremorBump hardware has a single H-bridge. A second H-bridge must be added to the design before this configuration can be used.

<s>

*The "Gold Standard" for fully jamming the tremor circuit by targeting both the "top" and "bottom" muscle groups of the arm.*

#### **Pair 1: The Inner Side (Channel 1 - Flexors)**
| **Location** | **Patient Instructions (Normal Language)** | **Clinical Notes (Medical Language)** |
| :--- | :--- | :--- |
| **Wrist** | Place one sticker in the **center of your inner wrist**, where you would feel a pulse. | Place electrode over the **median nerve** at the volar aspect of the wrist. |
| **Forearm** | Place the second sticker on your inner forearm, **four fingerbreadths** down from the crease of your elbow. | Position electrode over the **Flexor Carpi Radialis (FCR) motor point**, distal to the bicep tendon. |

#### **Pair 2: The Outer Side (Channel 2 - Extensors)**
| **Location** | **Patient Instructions (Normal Language)** | **Clinical Notes (Medical Language)** |
| :--- | :--- | :--- |
| **Wrist** | Place one sticker on the **back of your wrist**, on the outer thumb-side edge. | Place electrode over the **radial nerve** branch at the posterior/lateral wrist. |
| **Forearm** | Place the second sticker on the top of your forearm, **two fingerbreadths** down from the outer "funny bone" of your elbow. | Position electrode over the **Extensor Carpi Radialis (ECR) motor point**, distal to the lateral epicondyle. |

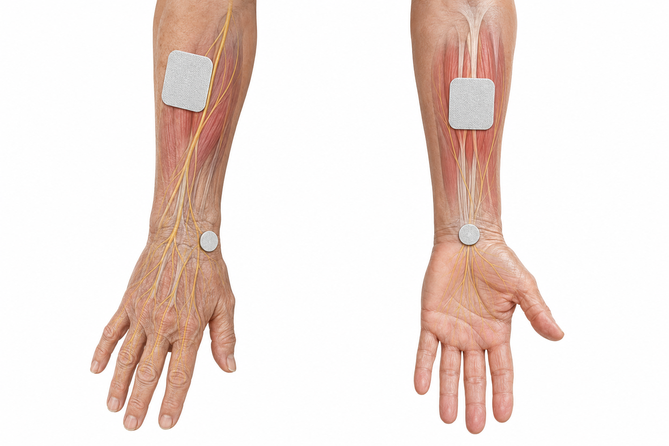
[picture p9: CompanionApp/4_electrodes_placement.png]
4-electrode dual-channel placement showing inner and outer pairs on both forearms


### **Pairing and Connection Logic**
To ensure the electrical circuit works correctly, you must pair the electrodes **Inner-to-Inner** and **Outer-to-Outer**:

1.  **Channel 1 (Inner Circuit):** Connect the two wires from the first plug to the two electrodes on the **palm-side** (Inner Wrist + Inner Forearm). This manages the "downward" flexing motion.
2.  **Channel 2 (Outer Circuit):** Connect the two wires from the second plug to the two electrodes on the **back-side** (Outer Wrist + Outer Forearm). This manages the "upward" extending motion.

### **Final Verification**
Once connected:
1.  **Syncing:** If using a device like **OpenXstim**, the device will alternate between these two pairs.
2.  **Sensation:** Ensure both channels provide a comfortable "pins and needles" feeling without causing the fingers to curl or the wrist to jump.
3.  **Duration:** Standard sessions last **20 to 40 minutes**, often providing relief that lasts for an hour or more after the session ends.

</s>

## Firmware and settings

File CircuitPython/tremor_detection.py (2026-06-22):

# SPDX-FileCopyrightText: 2026
# SPDX-License-Identifier: MIT

"""
CircuitPython 9.x tremor-synchronized stimulation  --  v7

Hardware:
- Adafruit QT Py ESP32-S3  (BLE required; ESP32-S2 has no Bluetooth)
- BNO055 on I2C  (NDOF fusion mode, default)
- H-bridge:  board.MOSI -> h_bridge_1,  board.MISO -> h_bridge_2
- Onboard NeoPixel for state / polarity indication

Detection concept:
- Sample gyro at SAMPLE_HZ.  Remove slowly adapting DC bias.
- Track dominant tremor axis with a 3-D direction EWMA (no cardinal snapping).
  If USE_WORLD_FRAME=True, rotate gyro into world frame via BNO055 quaternion
  before axis tracking so arm movement does not confuse the axis estimate.
- Detect hysteretic zero crossings; interpolate crossing time.
- Estimate tremor frequency from alternating crossing intervals.
- LOCKED: phase-correct stimulation schedule at every measured crossing.
  Dead-reckon between crossings with _advance_schedule.
- HOLDOVER: when signal is lost, continue stimulation at the last known
  frequency for HOLDOVER_TIMEOUT_S using the same scheduler.
- Fast re-lock: when signal returns from HOLDOVER, skip re-deriving the axis
  and require only RELOCKING_REQUIRED_CROSSES crossings.

BLE telemetry (v6 addition):
- Advertises as "TREMOR" using the custom service in ble_telemetry.py.
- Sends a 16-byte notify packet at BLE_NOTIFY_HZ (default 2 Hz).
- The ESP-IDF BLE stack runs as a FreeRTOS background task; the connection
  stays alive during blocking stimulation bursts (~30 ms).
- Connect from tremor_ble_recorder.html in Chrome / Edge.

This is experimental code. Validate on isolated test hardware only.
"""

import math
import time

import adafruit_bno055
import board
import busio
import digitalio
import neopixel
import supervisor


# -- HARDWARE PINS --------------------------------------------------------------

I2C_SCL          = board.SCL
I2C_SDA          = board.SDA
H_BRIDGE_1_PIN   = board.MOSI
H_BRIDGE_2_PIN   = board.MISO
NEOPIXEL_PIN     = board.NEOPIXEL
NEOPIXEL_COUNT   = 1
NEOPIXEL_BRIGHTNESS = 0.25


# -- TIMING & SAMPLE RATE -------------------------------------------------------

SAMPLE_HZ          = 75.0
SAMPLE_DT          = 1.0 / SAMPLE_HZ
MIN_TREMOR_HZ      = 2.0
MAX_TREMOR_HZ      = 8.0
MIN_HALF_PERIOD_S  = 0.5 / MAX_TREMOR_HZ   # 0.0625 s
MAX_HALF_PERIOD_S  = 0.5 / MIN_TREMOR_HZ   # 0.250  s


# -- STATE LABELS ---------------------------------------------------------------

UNLOCKED = "UNLOCKED"
LOCKING  = "LOCKING"
LOCKED   = "LOCKED"
HOLDOVER = "HOLDOVER"


# -- STIMULATION PARAMETERS -----------------------------------------------------

PEAK_POS = "(+)"
PEAK_NEG = "(-)"

PHASE_US                 = 250
INTERPHASE_GAP_US        = 1
INTERNAL_PULSE_HZ        = 200
STIM_DUTY_CYCLE          = 0.125
HOLDOVER_DUTY_SCALE      = 0.5
# 0.0 = stimulate at predicted peak; 0.5 = half period after peak
STIM_PHASE_OFFSET_CYCLES = 0.0
MIN_STIM_INTERVAL_S      = 0.050


# -- DETECTOR TUNING ------------------------------------------------------------

GYRO_BIAS_TAU_S      = 2.0    # gyro DC drift removal (4.0 by original design)

AXIS_LOCKING_TAU_S   = 0.35   # axis EWMA time constant during LOCKING (fast)
AXIS_LOCKED_TAU_S    = 2.0    # axis EWMA time constant during LOCKED  (slow)

AMP_ENV_TAU_S        = 0.30   # projected-signal envelope
THRESHOLD_FRACTION   = 0.28   # hysteresis band = amp_env * this
MIN_CROSS_THRESHOLD_DPS = 0.8
MIN_LOCK_ENV_DPS     = 2.0    # minimum envelope to consider signal valid

# Cold-start locking: require this many alternating crossings.
LOCKING_REQUIRED_ALTERNATING_CROSSES = 4
# Fast re-lock after HOLDOVER (axis already known): fewer crossings needed.
RELOCKING_REQUIRED_CROSSES           = 2
LOCKING_TIMEOUT_S     = 2.0   # abort LOCKING if no lock within this time
LOCKED_MISS_TIMEOUT_S = 1.2   # LOCKED -> HOLDOVER if no valid signal this long
# LOCKED -> HOLDOVER if no zero crossing for this long (catches wrong-axis freeze).
# Two full slow-tremor half-periods: tolerates one missed crossing.
LOCKED_NO_CROSS_TIMEOUT_S = 2.0 * MAX_HALF_PERIOD_S   # = 0.5 s

HOLDOVER_TIMEOUT_S   = 5.0    # HOLDOVER -> UNLOCKED if still no signal

FREQ_ALPHA_LOCKING   = 0.35   # frequency EMA blend during LOCKING
FREQ_ALPHA_LOCKED    = 0.18   # frequency EMA blend during LOCKED
FREQ_ALPHA_SCHED     = 0.08   # sched_hz EMA blend -- slower, for stable dead-reckoning

# If True, rotate sensor-frame gyro into world frame via BNO055 quaternion.
# Requires BNO055 NDOF fusion mode (the default). Falls back to sensor-frame
# automatically when bno.quaternion returns None (uncalibrated / wrong mode).
USE_WORLD_FRAME = True

# BLE telemetry notify rate. 2 Hz is enough for smooth live display and keeps
# BLE overhead well below 1% of loop time.
BLE_NOTIFY_HZ = 2.0

# flags byte bits in BLE packet:
#   bit 0  stim_enabled  state is LOCKED or HOLDOVER (stimulation may fire)
#   bit 1  polarity_ok   axis polarity has been established

ENABLE_FREQUENCY_TRACING = True   # 1-Hz state/frequency dump
ENABLE_LED_TRACING        = False    # print each LED_NEG ON event with interval
DEBUG_EVERY_S             = 1.0


# -- LED COLORS -----------------------------------------------------------------

LED_OFF           = (0,   0,   0)
LED_POS           = (200, 0, 200)
LED_NEG           = (0, 200,   0)
LED_LOCKING       = (8,   8,   0)
LED_UNLOCKED      = (0,   0,   8)
LED_HOLDOVER_STIM = (16, 16,  16)


# -- VECTOR & QUATERNION MATH  (pure functions, no heap allocation) -------------

def safe_print(*args):
    if supervisor.runtime.usb_connected:
        print(*args)


def v_add(a, b):    return (a[0]+b[0],  a[1]+b[1],  a[2]+b[2])
def v_sub(a, b):    return (a[0]-b[0],  a[1]-b[1],  a[2]-b[2])
def v_scale(a, s):  return (a[0]*s,     a[1]*s,     a[2]*s)
def v_dot(a, b):    return  a[0]*b[0] + a[1]*b[1] + a[2]*b[2]
def v_norm(a):      return  math.sqrt(v_dot(a, a))
def v_cross(a, b):  return (a[1]*b[2] - a[2]*b[1],
                             a[2]*b[0] - a[0]*b[2],
                             a[0]*b[1] - a[1]*b[0])


def v_normalize(a, fallback=(1.0, 0.0, 0.0)):
    n = v_norm(a)
    if n <= 1e-6:
        return fallback
    return (a[0]/n, a[1]/n, a[2]/n)


def exp_alpha(dt, tau):
    """EMA blending factor for time step dt and time constant tau."""
    if tau <= 0.0:
        return 1.0
    return 1.0 - math.exp(-dt / tau)


def clamp(x, lo, hi):
    return lo if x < lo else (hi if x > hi else x)


def q_conjugate(q):
    """Quaternion conjugate.  q = (w, x, y, z)."""
    return (q[0], -q[1], -q[2], -q[3])


def q_mul(p, q):
    """Hamilton product of two quaternions."""
    pw, px, py, pz = p
    qw, qx, qy, qz = q
    return (
        pw*qw - px*qx - py*qy - pz*qz,
        pw*qx + px*qw + py*qz - pz*qy,
        pw*qy - px*qz + py*qw + pz*qx,
        pw*qz + px*qy - py*qx + pz*qw,
    )


def q_rotate_vec(q, v):
    """Rotate vector v by unit quaternion q  (sandwich product q*v*q*)."""
    qv = (0.0, v[0], v[1], v[2])
    r  = q_mul(q_mul(q, qv), q_conjugate(q))
    return (r[1], r[2], r[3])


# -- HARDWARE LAYER -------------------------------------------------------------

_h1 = digitalio.DigitalInOut(H_BRIDGE_1_PIN)
_h1.direction = digitalio.Direction.OUTPUT
_h1.value = False

_h2 = digitalio.DigitalInOut(H_BRIDGE_2_PIN)
_h2.direction = digitalio.Direction.OUTPUT
_h2.value = False

pixels = neopixel.NeoPixel(NEOPIXEL_PIN, NEOPIXEL_COUNT,
                            brightness=NEOPIXEL_BRIGHTNESS, auto_write=True)
pixels[0] = LED_OFF


def bridge_idle():
    _h1.value = False
    _h2.value = False


def _bridge_positive():
    _h1.value = False
    _h2.value = True


def _bridge_negative():
    _h1.value = True
    _h2.value = False


def run_biphasic_burst(tremor_hz, polarity, holdover=False):
    """Deliver a symmetric biphasic burst.  Blocks for the burst duration.
    Returns number of pulses delivered."""
    if tremor_hz <= 0.0:
        return 0

    duty     = STIM_DUTY_CYCLE * (HOLDOVER_DUTY_SCALE if holdover else 1.0)
    burst_s  = duty / tremor_hz
    n_pulses = max(1, int(round(burst_s * INTERNAL_PULSE_HZ)))

    pixels[0] = (LED_HOLDOVER_STIM if holdover
                 else (LED_POS if polarity == PEAK_POS else LED_NEG))

    period_s = 1.0 / INTERNAL_PULSE_HZ
    pulse_s  = (PHASE_US * 2 + INTERPHASE_GAP_US) / 1_000_000.0
    idle_s   = max(0.0, period_s - pulse_s)

    for _ in range(n_pulses):
        _bridge_positive()
        time.sleep(PHASE_US / 1_000_000.0)
        bridge_idle()
        time.sleep(INTERPHASE_GAP_US / 1_000_000.0)
        _bridge_negative()
        time.sleep(PHASE_US / 1_000_000.0)
        bridge_idle()
        if idle_s > 0.0:
            time.sleep(idle_s)

    pixels[0] = LED_OFF
    return n_pulses


# -- TREMOR DETECTOR ------------------------------------------------------------

class TremorDetector:
    """
    3-D gyro tremor detector with axis-locked zero-crossing detection.

    Public read fields used by the main loop:
      state               - UNLOCKED / LOCKING / LOCKED / HOLDOVER
      tremor_hz           - live smoothed frequency estimate (responsive)
      sched_hz            - heavily filtered frequency for dead-reckoning scheduler
      stim_hz             - scheduling frequency (= tremor_hz in LOCKED,
                            frozen snapshot in HOLDOVER)
      amp_env             - axis-projected amplitude envelope (deg/s); used for
                            internal thresholds and crossing detection
      mag_env             - 3-D gyro magnitude envelope (deg/s); axis-independent,
                            more sensitive; use this for clinical amplitude reporting
      next_stim_t         - monotonic time of next stimulation (None = none scheduled)
      next_stim_polarity  - PEAK_POS or PEAK_NEG
      last_stim_polarity  - polarity of the most recently fired stim
      polarity_locked     - True once the tremor axis sign has been established
      came_from_holdover  - True while in the fast re-lock path

    Call update(gyro_dps, quat, now) at SAMPLE_HZ.
    After a stim fires, the main loop must set next_stim_t = None and call
    _advance_schedule(now) to arm the next event.
    """

    def __init__(self):
        # Fields that survive preserve_axis resets are initialised here so
        # they always exist regardless of which reset path runs first.
        self.bias            = (0.0, 0.0, 0.0)
        self.axis            = (1.0, 0.0, 0.0)
        self.axis_ref        = (1.0, 0.0, 0.0)
        self.polarity_locked = False
        self.tremor_hz       = 0.0
        self.sched_hz        = 0.0
        self._reset(preserve_axis=False)  # sets amp_env, mag_env, and all other fields

    # -- Public update ----------------------------------------------------------

    def update(self, gyro_vec, quat, now):
        """Process one gyro sample.
        Returns (cross_t, direction) on a valid crossing, else None."""
        if self.prev_t is None:
            self.prev_t = now
            return None

        dt = now - self.prev_t
        if dt <= 0.0 or dt > 0.1:
            dt = SAMPLE_DT

        # 1. Bias removal (always sensor frame so the bias estimate stays
        #    valid regardless of arm orientation changes).
        ba        = exp_alpha(dt, GYRO_BIAS_TAU_S)
        self.bias = v_add(v_scale(self.bias, 1.0 - ba), v_scale(gyro_vec, ba))
        motion    = v_sub(gyro_vec, self.bias)

        # 2. Optional world-frame rotation via BNO055 quaternion.
        if USE_WORLD_FRAME and quat is not None:
            motion = q_rotate_vec(quat, motion)

        # 3. Axis tracking.
        self._update_axis(motion, dt)

        # 4. Project onto current best axis and update envelope.
        ref      = self.axis_ref if self.polarity_locked else self.axis
        amp      = v_dot(motion, ref)
        self._update_envelope(amp, v_norm(motion), dt)

        # 5. All state transitions live here and nowhere else.
        self._update_state(now)

        # 6. HOLDOVER -- pure dead-reckoning, no crossing logic.
        if self.state == HOLDOVER:
            if self.next_stim_t is None:
                self._advance_schedule(now)
            self.prev_amp = amp
            self.prev_t   = now
            return None

        # 7. Zero-crossing detection (UNLOCKED / LOCKING / LOCKED).
        crossing = None
        if self.prev_amp is not None:
            crossing = self._detect_crossing(amp, now, dt)

        if crossing is not None:
            cross_t, direction = crossing
            self.last_crossing_t = now
            self._process_crossing(cross_t, direction)

        # 8. Dead-reckoning fallback if LOCKED and no stim is queued yet.
        if self.state == LOCKED and self.next_stim_t is None:
            self._advance_schedule(now)

        self.prev_amp = amp
        self.prev_t   = now
        return crossing

    # -- State machine ----------------------------------------------------------

    def _update_state(self, now):
        """All state transitions in one place.
        Each branch returns immediately so one call produces at most one hop."""

        if self.state == UNLOCKED:
            if self.amp_env >= MIN_LOCK_ENV_DPS:
                self.state              = LOCKING
                self.locking_started_t  = now
                self.last_signal_t      = now
                self.last_crossing_t    = now
                self.alternating_crosses = 0
                self.last_cross_t       = None
                self.last_cross_dir     = 0
                if not self.came_from_holdover:
                    # Cold start: reset axis polarity for a clean search.
                    self.polarity_locked = False
                self._required_crosses  = (RELOCKING_REQUIRED_CROSSES
                                           if self.came_from_holdover
                                           else LOCKING_REQUIRED_ALTERNATING_CROSSES)
            return

        if self.state == LOCKING:
            if self.amp_env >= MIN_LOCK_ENV_DPS:
                self.last_signal_t = now
            timed_out   = now - self.locking_started_t > LOCKING_TIMEOUT_S
            lost_signal = now - self.last_signal_t     > LOCKED_MISS_TIMEOUT_S
            if timed_out or lost_signal:
                self._reset(preserve_axis=False)
            return

        if self.state == LOCKED:
            if self.amp_env >= MIN_LOCK_ENV_DPS:
                self.last_signal_t = now
            signal_gap = now - self.last_signal_t   > LOCKED_MISS_TIMEOUT_S
            cross_gap  = (self.last_crossing_t is not None and
                          now - self.last_crossing_t > LOCKED_NO_CROSS_TIMEOUT_S)
            if signal_gap or cross_gap:
                self._start_holdover(now)
            return

        if self.state == HOLDOVER:
            if now - self.holdover_started_t > HOLDOVER_TIMEOUT_S:
                self._reset(preserve_axis=False)
                return
            if self.amp_env >= MIN_LOCK_ENV_DPS:
                # Signal returned: fast re-lock, preserving axis geometry.
                self._reset(preserve_axis=True)
            return

    # -- Signal processing ------------------------------------------------------

    def _update_axis(self, motion, dt):
        """Unified EWMA axis tracker used in both LOCKING and LOCKED phases.

        LOCKING: fast time constant, anti-flip vs rolling self.axis.
        LOCKED:  slow time constant, anti-flip vs FROZEN self.axis_ref.
        The two cases share identical math; only tau and the reference differ."""
        if v_norm(motion) < MIN_CROSS_THRESHOLD_DPS:
            return
        candidate = v_normalize(motion, self.axis)
        if self.polarity_locked:
            if v_dot(candidate, self.axis_ref) < 0.0:
                candidate = v_scale(candidate, -1.0)
            a = exp_alpha(dt, AXIS_LOCKED_TAU_S)
        else:
            if v_dot(candidate, self.axis) < 0.0:
                candidate = v_scale(candidate, -1.0)
            a = exp_alpha(dt, AXIS_LOCKING_TAU_S)
        mixed     = v_add(v_scale(self.axis, 1.0 - a), v_scale(candidate, a))
        self.axis = v_normalize(mixed, self.axis)

    def _update_envelope(self, amp, mag, dt):
        a            = exp_alpha(dt, AMP_ENV_TAU_S)
        self.amp_env = self.amp_env * (1.0 - a) + abs(amp) * a
        self.mag_env = self.mag_env * (1.0 - a) + mag * a

    def _compute_threshold(self):
        return max(self.amp_env * THRESHOLD_FRACTION, MIN_CROSS_THRESHOLD_DPS)

    def _detect_crossing(self, amp, now, dt):
        """Hysteresis arming + zero-crossing detection + linear interpolation.
        Returns (cross_t, direction) or None.  Pure detection, no side effects."""
        threshold = self._compute_threshold()

        if amp > threshold:
            self.armed_neg = True
        elif amp < -threshold:
            self.armed_pos = True

        prev      = self.prev_amp
        direction = 0

        if prev < 0.0 and amp >= 0.0 and self.armed_pos:
            direction      = 1
            self.armed_pos = False
        elif prev > 0.0 and amp <= 0.0 and self.armed_neg:
            direction      = -1
            self.armed_neg = False

        if direction == 0:
            return None

        denom   = amp - prev
        frac    = clamp(-prev / denom, 0.0, 1.0) if abs(denom) > 1e-6 else 1.0
        cross_t = self.prev_t + frac * dt
        return (cross_t, direction)

    def _update_frequency(self, half_period_s):
        """EMA update of tremor_hz from a measured half-period."""
        hz = 1.0 / (half_period_s * 2.0)
        if hz < MIN_TREMOR_HZ or hz > MAX_TREMOR_HZ:
            return
        if self.state == LOCKED and self.amp_env < MIN_LOCK_ENV_DPS:
            return
        if self.tremor_hz <= 0.0:
            self.tremor_hz = hz
        else:
            alpha          = FREQ_ALPHA_LOCKED if self.state == LOCKED else FREQ_ALPHA_LOCKING
            self.tremor_hz = self.tremor_hz * (1.0 - alpha) + hz * alpha
        # Keep stim_hz / sched_hz current during LOCKED/LOCKING.
        # _start_holdover freezes them by not updating in HOLDOVER state.
        if self.state != HOLDOVER:
            self.stim_hz = self.tremor_hz
            if self.sched_hz <= 0.0:
                self.sched_hz = self.tremor_hz
            else:
                self.sched_hz = (self.sched_hz * (1.0 - FREQ_ALPHA_SCHED)
                                 + self.tremor_hz * FREQ_ALPHA_SCHED)

    # -- Crossing processing ----------------------------------------------------

    def _process_crossing(self, cross_t, direction):
        """Half-period bookkeeping, frequency update, lock transition, and
        schedule phase-correction -- all triggered by one detected crossing."""
        if self.last_cross_t is not None:
            half_period_s = cross_t - self.last_cross_t
            if MIN_HALF_PERIOD_S <= half_period_s <= MAX_HALF_PERIOD_S:
                if direction != self.last_cross_dir:
                    self.alternating_crosses += 1
                    self._update_frequency(half_period_s)
                else:
                    # Two consecutive same-direction crossings: missed opposite.
                    self.alternating_crosses = 0
            else:
                self.alternating_crosses = 0

        prev_cross_dir      = self.last_cross_dir
        self.last_cross_t   = cross_t
        self.last_cross_dir = direction

        # LOCKING -> LOCKED: triggered by crossing count reaching the threshold.
        if self.state == LOCKING:
            if self.alternating_crosses >= self._required_crosses:
                self.state              = LOCKED
                self.locking_started_t  = None
                self.came_from_holdover = False
                if not self.polarity_locked:
                    self._lock_axis_polarity()

        # Phase-correct only on valid alternating crossings -- same guard as
        # frequency update -- so noise same-direction crossings do not shift the
        # stim schedule away from the actual tremor peak.
        if self.state == LOCKED and direction != prev_cross_dir:
            self._schedule_from_crossing(cross_t, direction)

    # -- Axis polarity ----------------------------------------------------------

    def _lock_axis_polarity(self):
        """Freeze the current axis as the polarity reference.
        This is the ONLY place axis_ref is ever written after __init__."""
        self.axis        = v_normalize(self.axis)
        self.axis_ref    = self.axis
        self.polarity_locked = True

    # -- Scheduler --------------------------------------------------------------

    def _schedule_from_crossing(self, cross_t, direction):
        """Phase-correct the stim schedule using a measured zero crossing.
        Overrides any existing next_stim_t with a phase-accurate value."""
        if self.tremor_hz <= 0.0:
            return
        period_s = 1.0 / self.tremor_hz
        polarity = PEAK_POS if direction > 0 else PEAK_NEG
        if self.target_polarity is not None and polarity != self.target_polarity:
            return                          # skip non-target crossings
        self.next_stim_t        = (cross_t
                                   + period_s * 0.25
                                   + period_s * STIM_PHASE_OFFSET_CYCLES)
        self.next_stim_polarity = polarity
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

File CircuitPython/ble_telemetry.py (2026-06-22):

# SPDX-FileCopyrightText: 2026
# SPDX-License-Identifier: MIT

"""
ble_telemetry.py

BLE telemetry helper for the tremor-synchronized stimulation prototype.

This version uses the normal CircuitPython BLE service-advertising pattern:

    advertisement = ProvideServicesAdvertisement(service)
    scan_response = Advertisement()
    scan_response.complete_name = "TREMOR"
    ble.start_advertising(advertisement, scan_response, interval=0.1)

Reason:
- A custom 128-bit service UUID is needed so Web Bluetooth can discover the
  telemetry service.
- The visible device name may not fit in the main advertisement.
- Therefore the name is placed in the scan response.

Packet format, little-endian, exactly 13 bytes:

    uint32  device_t_ms      raw milliseconds (wraps ~49 days)
    uint8   state_code       0=UNLOCKED 1=LOCKING 2=LOCKED 3=HOLDOVER 255=unknown
    uint16  sched_hz_x100    scheduling frequency × 100  (0.01 Hz resolution)
    uint16  tremor_hz_x100   measured frequency × 100    (0.01 Hz resolution)
    uint16  mag_env_x10      3-D magnitude envelope × 10 (0.1 deg/s resolution)
    uint16  stim_count       cumulative stimulation count (wraps at 65535)
"""

import struct

import microcontroller

from adafruit_ble import BLERadio
from adafruit_ble.advertising import Advertisement
from adafruit_ble.advertising.standard import ProvideServicesAdvertisement
from adafruit_ble.attributes import Attribute
from adafruit_ble.characteristics import Characteristic
from adafruit_ble.services import Service
from adafruit_ble.uuid import VendorUUID


TREMOR_SERVICE_UUID  = VendorUUID("7f6d0001-6f7a-4f4e-9a8b-3b7f4b000001")
TELEMETRY_CHAR_UUID  = VendorUUID("7f6d0002-6f7a-4f4e-9a8b-3b7f4b000001")
SETTINGS_CHAR_UUID   = VendorUUID("7f6d0003-6f7a-4f4e-9a8b-3b7f4b000001")

# Settings struct — 8 bytes, little-endian, stored in microcontroller.nvm[0:8]
_SETTINGS_LEN      = 8
_SETTINGS_VERSION  = 1
_IDX_VERSION       = 0   # uint8: struct version, must == _SETTINGS_VERSION
_IDX_ARM_SIDE      = 1   # uint8: 0=not set, 1=left, 2=right
_IDX_PHASE_OVR     = 2   # uint8: 0=auto, 1=positive crossing, 2=negative crossing
# bytes 3-7: reserved (0xFF)
_SETTINGS_DEFAULTS = bytes([_SETTINGS_VERSION, 0, 0, 0xFF, 0xFF, 0xFF, 0xFF, 0xFF])
_NVM_START         = 0   # settings occupy nvm[0:8]

STATE_UNKNOWN = 255
STATE_CODES = {
    "UNLOCKED": 0,
    "LOCKING":  1,
    "LOCKED":   2,
    "HOLDOVER": 3,
}

_PACKET_FORMAT = "<LBHHHH"
_PACKET_LEN = 13
_ZERO_PACKET = bytes(_PACKET_LEN)


class TremorTelemetryService(Service):
    uuid = TREMOR_SERVICE_UUID

    telemetry = Characteristic(
        uuid=TELEMETRY_CHAR_UUID,
        properties=Characteristic.READ | Characteristic.NOTIFY,
        read_perm=Attribute.OPEN,
        write_perm=Attribute.NO_ACCESS,
        max_length=_PACKET_LEN,
        fixed_length=True,
        initial_value=_ZERO_PACKET,
    )

    settings = Characteristic(
        uuid=SETTINGS_CHAR_UUID,
        properties=Characteristic.READ | Characteristic.WRITE,
        read_perm=Attribute.OPEN,
        write_perm=Attribute.OPEN,
        max_length=_SETTINGS_LEN,
        fixed_length=True,
        initial_value=bytes(_SETTINGS_LEN),
    )


class BLETremorTelemetry:
    def __init__(self, name="TREMOR", notify_hz=2.0, debug=True):
        self.name = name
        self.notify_hz = notify_hz
        self.notify_interval_s = 1.0 / notify_hz if notify_hz > 0.0 else 1.0
        self.debug = debug

        self.ble = BLERadio()
        try:
            self.ble.name = name
        except Exception:
            pass

        self.service = TremorTelemetryService()

        # Main advertisement: includes the custom service UUID.
        self.advertisement = ProvideServicesAdvertisement(self.service)

        # Scan response: includes the visible device name.
        self.scan_response = Advertisement()
        self.scan_response.complete_name = name
        self.scan_response.short_name = name

        self._last_notify_t = -9999.0
        self._packet = bytearray(_PACKET_LEN)
        self._advertising = False
        self._last_connected = False

        nvm_raw = bytes(microcontroller.nvm[_NVM_START : _NVM_START + _SETTINGS_LEN])
        self._settings = self._coerce_settings(nvm_raw)
        self._last_settings = bytes(self._settings)
        self.service.settings = self._settings

    def address_string(self):
        try:
            address = self.ble.address_bytes
        except Exception:
            return "unknown"

        parts = []
        for b in address:
            parts.append("%02X" % b)
        return ":".join(parts)

    def debug_print_identity(self):
        print("BLE name", self.name)
        print("BLE address", self.address_string())
        print("BLE service", "7f6d0001-6f7a-4f4e-9a8b-3b7f4b000001")
        print("BLE telemetry", "7f6d0002-6f7a-4f4e-9a8b-3b7f4b000001")
        print("BLE settings", "7f6d0003-6f7a-4f4e-9a8b-3b7f4b000001")
        print("BLE settings arm_side=%d phase_ovr=%d" % (
            self._settings[_IDX_ARM_SIDE], self._settings[_IDX_PHASE_OVR]))

    def start_advertising(self):
        if self.ble.connected:
            return
        if self._advertising:
            return
        try:
            self.ble.start_advertising(
                self.advertisement,
                self.scan_response,
                interval=0.1,
            )
            self._advertising = True
            if self.debug:
                print("BLE advertising", self.name, self.address_string())
        except Exception as exc:
            self._advertising = False
            if self.debug:
                print("BLE advertising failed", repr(exc))

    def stop_advertising(self):
        if not self._advertising:
            return
        try:
            self.ble.stop_advertising()
        except Exception:
            pass
        self._advertising = False

    def maintain(self):
        connected = self.ble.connected

        if connected != self._last_connected:
            self._last_connected = connected
            if self.debug:
                print("BLE connected", connected)

        if connected:
            self._advertising = False
            return

        self.start_advertising()

    def connected(self):
        return self.ble.connected

    def update(
        self,
        now,
        state,
        sched_hz,
        tremor_hz,
        mag_env,
        stim_count,
        allow_send=True,
    ):
        self.maintain()

        if not allow_send:
            return False
        if not self.ble.connected:
            return False
        if now - self._last_notify_t < self.notify_interval_s:
            return False
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

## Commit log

2026-06-20 Move README to repo root and add docs
    - Moved README.md from CircuitPython/ to repo root
    - Added safety disclaimer (40 V, risks, sole responsibility)
    - Added directory structure overview
    - Expanded project description to four parts (hardware, firmware, BLE, web app)
    - Added electrode and gel recipe reference in Hardware section
    - Added docs/conductive_electrode_gel_recipe.md with storage/shelf-life guidance
2026-06-20 Add hardware files
    BOM and 3D-printable enclosure STLs (main box, cog, sensor box).
    [TremorBumpBox.stl, TremorBumpCog.stl, TremorBumpSensorBox.stl]
2026-06-20 Add SAFETY.md and tighten README disclaimer
    Move full safety warning into dedicated SAFETY.md covering design-specific
    risks (no kill switch, no current limiting, DC-on-lockup), contraindications,
    and rules for use. Replace README blockquote with a short callout linking to it.
2026-06-21 Rename and update SES docs
    - Rename 'SES for Hand Tremors in Senior Patients.md' to SES_Clinical_Reference.md
    - Update cross-links in SES_Overview.md accordingly
2026-06-21 CompanionApp: switch app icons to iconC (shield + hand + heartbeat)
2026-06-21 docs: add electrode placement diagram to manual
2026-06-21 CompanionApp: add Help screen with electrode placement guide
2026-06-21 docs: add electrode placement diagram
2026-06-21 Move electrode_placement.png to CompanionApp/ and update references
2026-06-21 CompanionApp: fix start screen height inconsistency
    - Clear start-screen error whenever returning to start (was only
    cleared in startRecording(), leaving stale errors visible after
    back-navigation from any other screen)
    - Switch min-height from 100vh to 100dvh so the card tracks the
    dynamic viewport on Android (soft nav bar show/hide)
2026-06-21 CompanionApp: debug purple bg, fix layout, bust SW cache
    - sw.js: bump cache to v2 so browsers pick up new HTML
    - Background purple for visual confirmation that update landed
    - Reduce .app padding 20px→4px and .card margin 16px→4px to
    eliminate the large top grey gap
    - .card.primary-screen: switch from min-height to fixed height
    using 100svh so card never grows when error appears and
    never expands when Chrome address bar hides
2026-06-21 CompanionApp: fix card height and inter-card gap, cache v4
    - 100svh -> 100dvh: svh uses Chrome's minimum viewport (address bar
    visible) which is smaller than the actual visible area, leaving
    card 2 peeking; dvh tracks the current viewport dynamically
    - card margin 4px -> 8px: gives 16px gap between cards
    - app padding-top 8px -> 4px: keeps top gap = 4+8 = 12px (= sides)
2026-06-21 CompanionApp: disable pull-to-refresh, increase inter-card gap, cache v5
    - overscroll-behavior-y: none — prevents Chrome pull-to-refresh from
    reloading the page and causing card height to change
    - .card + .card margin-top: 16px — gap between cards is now
    8px (card bottom) + 16px (next card top) = 24px (1.5x the previous 16px)
    without affecting the top gap of the primary card
2026-06-21 Add 2- and 4-electrode placement images to app help and manual (v0.1-alpha.9)
    - 2_electrodes_placement.png: after Config A table in both files
    - 4_electrodes_placement.png: after Config B intro in both files
    (replaces old electrode_placement.png reference in the manual)
2026-06-21 Strike out Config B (4-electrode) with hardware limitation note (v0.1-alpha.10)
    Config B requires a second H-bridge for 180-degree phase-offset firing.
    Current hardware has one H-bridge. Content kept but struck through in
    both the app help screen and the manual.
2026-06-21 Add Backlog.md: fix stimulation phase for 2-electrode system
    Current firmware fires at both pi/2 and 3pi/2 per tremor cycle.
    For the single-channel 2-electrode hardware this is wrong.
    Correct phase is TBD — depends on arm side and sensor orientation.
    Must fire when arm is closest to body during tremor cycle.
2026-06-21 Backlog: plan automatic phase detection via gravity vector + arm side setting
2026-06-22 Backlog: plan auto left/right detection via startup calibration posture
2026-06-22 Backlog: add full spec planning for Spec A (arm detection) and Spec B (phase-correct stimulation)
    User stories, acceptance criteria, firmware + app requirements,
    LED state table, BLE packet extension, documentation requirements,
    and open questions for both specs.
2026-06-22 Backlog: NVM as primary arm-side storage, gravity detect as fallback
    microcontroller.nvm[0] stores arm side across power cycles.
    App sets it via BLE write — no calibration posture needed after first use.
    Gravity auto-detect retained as first-boot fallback when NVM is empty.
    Spec A firmware requirements updated accordingly.
2026-06-22 Backlog: plan BLE settings characteristic architecture
    - New characteristic 7f6d0003 (read+write) in existing service
    - 8-byte versioned settings struct with arm_side, calibration params, reserved bytes
    - App protocol: read-on-connect, write-then-read-back verification
    - Firmware: validate struct_version and field ranges before NVM write
    - Device NVM is single source of truth; app never uses localStorage for settings
2026-06-22 Backlog: full rewrite — clean structure, fix errors, remove outdated content
    - Main goal stated clearly at top: fire at one phase per cycle, not both
    - Removed outdated 'possible solutions 1/2/3' and speckit references
    - Resolved FW-A7 / settings-char conflict: settings char is the only write path
    - Fixed LED colour conflict: left arm = magenta (not yellow = LOCKING)
    - Closed answered open question re BLE characteristic for arm override
    - Constraint 1 (arm posture for phase) moved from Feature 2 to Feature 3
    - NVM byte index corrected: arm_side is byte 1 (struct field), not byte 0 (version)
    - fire_polarity described as positive/negative crossing, not pi/2 / 3pi/2
    - Each feature has separat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
2026-06-22 Backlog: remove all auto-detection, LED arm-side colours, and both-phase fallback
    - No gravity auto-detect, no LED colour coding for arm side, no ambiguity fallback
    - arm_side not set = no stimulation, clear app message, Start button disabled
    - Removed telemetry packet extension (bytes 13/14): settings trusted from connect-time read
    - Added session data header: deviceSettings stored in every session record and export
    - Settings struct simplified: removed calibration_wait_s and lateral_threshold_x10
    - Feature 3 degenerate posture: no stimulation (not fall back to both phases)
    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
2026-06-22 Update electrode image, remove old filename, update references
2026-06-22 Feature 1: BLE settings characteristic (7f6d0003) + NVM storage (v0.1-alpha.11)
    Firmware (ble_telemetry.py):
    - Add SETTINGS_CHAR_UUID 7f6d0003 with READ+WRITE permissions
    - Settings struct v1: struct_version, arm_side, fire_polarity_override, 5 reserved bytes
    - Read/coerce NVM[0:8] on init; initialise characteristic from NVM
    - _coerce_settings(): substitutes defaults for uninitialised (0xFF) NVM
    - check_settings_write(): polls for central writes, validates, writes to NVM, returns changed fields
    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
2026-06-22 Fix 3 bugs found in Feature 1 review (v0.1-alpha.12)
    1. check_settings_write(): version check was dead code — _coerce_settings()
    always overwrote version before check. Now checks raw current[_IDX_VERSION]
    before calling _coerce_settings().
    2. exportSummaryJson(): explicit session field whitelist omitted deviceSettings,
    silently dropping the session header from every JSON export. Added it.
    3. device-settings-offline: missing initial 'hidden' class in HTML; showConfigScreen()
    always corrected it, but initial state was inconsistent. Fixed.
    [ble_telemetry.py]
2026-06-22 Feature 2: arm-side gate — no stimulation or recording without arm side set (v0.1-alpha.13)
    Firmware (tremor_detection.py):
    - Add arm_side != 0 guard to stimulation gate; device locks normally
    but run_biphasic_burst() never fires if arm side is not configured
    Companion app (tremor_recorder.html):
    - Add .warning CSS class (amber) distinct from .error (red)
    - Start screen: arm-side status line + amber warning block (hidden until connected)
    - updateArmSideDisplay(): shows arm side text, warning, and gates btn-start
    when arm_side == 0; called from showScreen("start"), startRecording finally,
    safeDisconnect, handleDisconnected
    - startRecording(): refreshes session.deviceSettings after co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
    [tremor_detection.py]
2026-06-22 Feature 3: phase-correct stimulation — single phase per cycle (v0.1-alpha.14)
    - Add v_cross() vector helper
    - Add compute_fire_polarity(): returns PEAK_POS, PEAK_NEG, or None.
    Checks arm_side, phase_override, and gravity degenerate case (arm
    near-vertical, |g_perp| < 1 m/s²). Auto mode selects polarity by
    arm side with documented assumption needing hardware validation.
    - TremorDetector._reset(): add target_polarity = None
    - _schedule_from_crossing(): skip crossings that don't match target_polarity
    - _advance_schedule(): full-period scheduling when target_polarity is set
    (one burst per tremor cycle); falls back to half-period alternating if None
    - Ma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
    [tremor_detection.py]
2026-06-22 firmware: make LED_POS visible (magenta) for single-phase Feature 3
    With Feature 3, right arm fires only at PEAK_POS. Old LED_POS (2,0,0)
    was nearly invisible dim red. Changed to (200,0,200) strong magenta so
    the single-phase burst is clearly visible.
